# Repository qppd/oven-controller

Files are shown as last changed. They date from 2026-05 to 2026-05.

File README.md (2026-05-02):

## Oven Controller – Arduino‑Uno Embedded System
*Compact, menu‑driven oven controller with temperature & humidity sensing, scheduling, and PID‑based heating.*

---

## Overview
The Arduino‑based Oven Controller runs on an **Arduino Uno (AVR)** and provides a complete solution for managing a small oven or drying chamber.

**Key features**
- Real‑time temperature (DS18B20) & humidity (DHT22) monitoring
- RTC‑driven scheduling & timer (DS3231 + TimeAlarms)
- Heater & exhaust fan control via two relays
- 20×4 I²C LCD UI with three tactile buttons for menu navigation
- PID temperature regulation (PID_v1) with configurable set‑point (60‑125 °C)
- Flexible architecture: each hardware block lives in its own `.h/.cpp` pair

**Typical use‑cases**
- Laboratory drying oven
- Small food‑processing oven
- DIY thermal curing chamber

---

## System Architecture
```
+-------------------+      +-------------------+      +-------------------+
|   Arduino Uno     | ---> |   Hardware       | ---> |   External Power |
| (main sketch)    |      | (sensors, relays) |      |   & Safety Devices|
+-------------------+      +-------------------+      +-------------------+

+-------------------+      +-------------------+      +-------------------+
|   LCD (I2C)       | <--> |   Buttons (3)    | <--> |   User Interaction|
+-------------------+      +-------------------+      +-------------------+

+-------------------+      +-------------------+      +-------------------+
|   PID Controller  | <--> |   Temperature    |      |   Heater Relay   |
+-------------------+      +-------------------+      +-------------------+

+-------------------+      +-------------------+      +-------------------+
|   RTC (DS3231)    | <--> |   Alarms/Timers  |      |   Exhaust Relay   |
+-------------------+      +-------------------+      +-------------------+
```
- **Modular code**: each peripheral (LCD, relays, buttons, DHT22, DS18B20, DS3231, PID) has its own header and implementation file.
- **Separation of concerns**: hardware initialization, UI rendering, sensor acquisition, and control logic are isolated, making extensions (e.g., Wi‑Fi, EEPROM) straightforward.

---

## Hardware Components
| Component | Model / Library | Purpose |
|---|---|---|
| Arduino Uno | ATmega328P | Core MCU |
| DS18B20 | OneWire + DallasTemperature | Temperature sensor (pin 7) |
| DHT22 | DHT library | Humidity sensor (pin 8) |
| DS3231 | RTClib | Real‑time clock & calendar |
| 2× Relay modules | Direct `digitalWrite` | Heater (pin 2) & Exhaust fan (pin 3) |
| 20×4 I²C LCD | LiquidCrystal_I2C (0x27) | UI display |
| 3× Tactile buttons | Pull‑up inputs (pins 4‑6) | Menu navigation (UP, DOWN, SELECT) |
| I²C bus lines | SDA=A4, SCL=A5 | LCD communication |

**Pin configuration** (see `PINS_CONF.h`)
| Pin | Function |
|-----|---|
| 2 | Heater relay |
| 3 | Exhaust relay |
| 4 | Button 1 (UP) |
| 5 | Button 2 (DOWN) |
| 6 | Button 3 (SELECT) |
| 7 | DS18B20 temperature sensor |
| 8 | DHT22 humidity sensor |
| A4  | I²C SDA (LCD) |
| A5  | I²C SCL (LCD) |

---

## Software Architecture
| Module | Description |
|---|---|
| **OvenController.ino** | Main sketch: state machine, `setup()` / `loop()`, UI rendering, button handling, safety checks. |
| **LCD_CONF** (`LCD_CONF.h/.cpp`) | Wraps `LiquidCrystal_I2C`; provides `initLCD()`, `clearLCD()`, and overloaded `setLCDText()` for various data types. |
| **RELAY_CONF** (`RELAY_CONF.h/.cpp`) | Initializes relay pins and exposes `setHeaterRelay(bool)` / `setExhaustRelay(bool)`. |
| **TACTILE_CONF** (`TACTILE_CONF.h/.cpp`) | Handles button debouncing, state flags, and forwards button events to `inputAction(int)`. |
| **DHT_CONF** (`DHT_CONF.h/.cpp`) | Simple wrapper class `DHT22Sensor` exposing `begin()` and `readHumidity()`. |
| **DS18B20_CONF** (`DS18B20_CONF.h/.cpp`) | Wrapper class `DS18B20Sensor` exposing `begin()` and `readTemperature()`. |
| **DS3231_CONF** (`DS3231_CONF.h/.cpp`) | Global `RTC_DS3231` instance, `dsInitRTC()` for init, `dsHandleRTC()` for alarm processing and periodic time sync. |
| **PID_CONF** (`PID_CONF.h/.cpp`) | PID tuning (`P=4`, `I=0`, `D=22`), set‑points, runtime variables, `initPID()` and `computePID()` that drive the heater relay via time‑proportional control. |

The **state machine** (`OvenState`) cycles through: `IDLE → SET_TEMP → SET_TIMER → READY → RUNNING → FINISHED → ERROR`. Button actions transition states, and the LCD reflects the current state.

---

## System Flow
1. **`setup()`**
   - Serial init, LCD init, button init, relay init, LED pin, RTC init, sensor init, PID init.
   - Displays "Oven Ready".
2. **`loop()`** (executed continuously)
   - **Input handling** – `setInputFlags()` → `resolveInputFlags()` → calls `inputAction()` based on button pressed.
   - **Sensor read** – humidity via `DHT22Sensor`, temperature via `DS18B20Sensor`.
   - **Safety check** – if temperature > 130 °C → `stopOven()`, state = `ERROR`.
   - **PID** – temperature updates `CURRENT_TEMPERATURE`; `computePID()` calculates heater PWM and toggles relay.
   - **RTC** – `dsHandleRTC()` advances alarms, syncs time every minute.
   - **UI** – `renderLCD()` draws the appropriate screen for the current state.
   - Small `delay(10)` to ease CPU load.

**Simplified flow diagram**
```
setup() ──► init all peripherals
   │
   ▼
loop()
 ├─► read buttons → inputAction()
 ├─► read humidity & temperature
 ├─► safety cut‑off?
 │   └─► stopOven() & ERROR state
 ├─► PID compute → heater relay
 ├─► dsHandleRTC() (alarms & sync)
 └─► renderLCD()
```

---

## User Interface (Buttons + LCD)
| Button | Function |
|---|---|
| **UP** (pin 4) | Increment set‑point / timer |
| **DOWN** (pin 5) | Decrement set‑point / timer |
| **SELECT** (pin 6) | Advance to next screen / confirm action / start / stop / reset |

**Screens**
| State | LCD Content |
|---|---|
| **IDLE** | Current temperature, setpoint, "Press SELECT". |
| **SET_TEMP** | "SET TEMP", current set‑point, `BTN1:+  BTN2:-  BTN3:NEXT`. |
| **SET_TIMER** | "SET TIMER", minutes, same button hints. |
| **READY** | Shows target temperature & timer, `BTN3: START`. |
| **RUNNING** | Live temperature vs. set‑point, remaining timer, `BTN3: STOP`. |
| **FINISHED** | "DONE!", "Time Complete", `BTN3: RESET`. |
| **ERROR** | "ERROR – Overtemp", `BTN3: RESET`. |

---

## Control Logic
- **Set‑point range**: 60 °C – 125 °C (clamped in `SET_TEMP`).
- **Timer**: User‑selected minutes (1 – 180 min). `Alarm.timerOnce()` schedules `ovenStopCallback()`.
- **Relay behavior**
  - **Exhaust**: Always on during `RUNNING` for safety.
  - **Heater**: Controlled by PID output (0‑255) via time‑proportional window (1 s).
- **Safety**: Over‑temperature (>130 °C) forces immediate shut‑off and enters `ERROR`.

**PID defaults** (editable in `PID_CONF.cpp`)
```cpp
double P = 4.0;
double I = 0.0;
double D = 22.0;
double TEMPERATURE_SETPOINT = 100.0; // °C
```

---

## Timer & Scheduling
- **`dsInitRTC()`**: Starts I²C, initializes the DS3231, sets time from compile‑time if battery lost, and seeds TimeAlarms.
- **`dsHandleRTC()`**: Calls `Alarm.delay(1000)` each loop to advance the alarm engine, and resynchronises the Arduino `time()` with the RTC every 60 s.
- **`ovenStartAlarm()` / `ovenStopAlarm()`**: Example callbacks (currently hard‑coded to a placeholder relay pin).
- **`ovenTimer = Alarm.timerOnce(timerMinutes*60, ovenStopCallback);`** schedules a one‑shot stop alarm.

---

## Getting Started
1. **Install Arduino IDE** (or compatible CLI).
2. **Add libraries** via Library Manager or `Sketch → Include Library → Manage Libraries`
| Library | Header |
|---|---|
| LiquidCrystal_I2C | `LiquidCrystal_I2C.h` |
| OneWire | `OneWire.h` |
| DallasTemperature | `DallasTemperature.h` |
| DHT sensor library | `DHT.h` |
| RTClib | `RTClib.h` |
| TimeLib | `TimeLib.h` |
| TimeAlarms | `TimeAlarms.h` |
| PID_v1 | `PID_v1.h` |
3. **Wire the hardware** (see pin table above).
4. Open `src/uno/OvenController/OvenController.ino` in the IDE, select **Arduino Uno**, and click **Upload**.
5. Power the board, open the Serial Monitor (9600 baud) to see debug output, and interact with the LCD using the three buttons.

---

## Dependencies
- **Arduino core** (`Arduino.h`)
- **LiquidCrystal_I2C** – I²C LCD driver
- **OneWire** & **DallasTemperature** – DS18B20 communication
- **DHT** – DHT22 humidity sensor
- **RTClib** – DS3231 RTC handling
- **TimeLib** – time utilities (`now()`, `setTime()`)
- **TimeAlarms** – alarm & timer scheduling
- **PID_v1** – PID control algorithm
All libraries are publicly available through the Arduino Library Manager.

---

## Future Improvements
- Full PID tuning (auto‑tune, different window sizes).
- Persistent storage of set‑points & timer via EEPROM.
- Wi‑Fi / ESP32 migration for remote monitoring & OTA updates.
- Mobile or web dashboard (MQTT, HTTP).
- Additional safety sensors (over‑current, door switch).

---

## Troubleshooting
| Symptom | Likely cause | Fix |
|---|---|-----|
| LCD stays blank or shows "LCD error" | Incorrect I²C address or wiring | Verify address (`0x27`) with an I²C scanner; check SDA/SCL connections. |
| `Alarm.freeAll()` warning in Serial | TimeAlarms bug when freeing non‑existent alarms | Ensure `ovenTimer` is valid before calling `Alarm.free()`. |
| Compile error: multiple `RTClib` versions | Duplicate library versions in sketchbook | Keep only one version of `RTClib` (prefer the latest). |
| Relays never trigger | Pins not set as outputs or missing power | Confirm `initRelays()` runs; measure voltage on relay pins. |
| Over‑temperature shutdown immediately | Sensor wiring error or faulty DS18B20 | Test sensor separately; replace if readings are nonsensical. |

---

## License
**MIT License** – feel free to use, modify, and distribute this code.

---

## Author

<div align="center">

**Created with dedication by [qppd](https://github.com/qppd)**



</div>

---

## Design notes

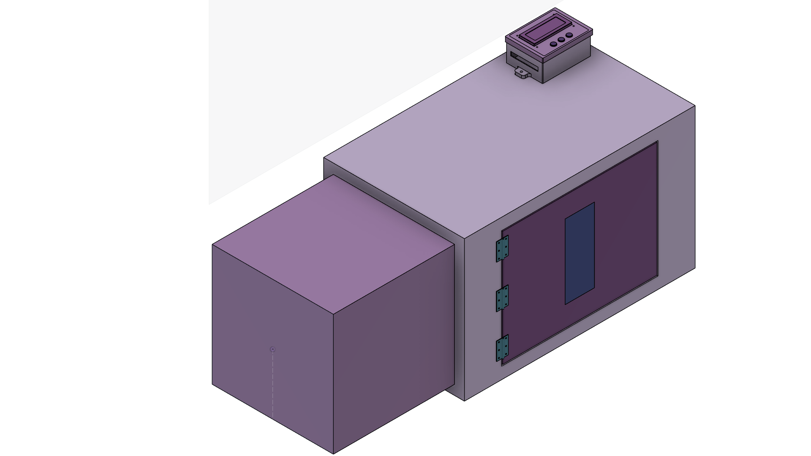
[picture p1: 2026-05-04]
fusion360/images/Oven_Controller_FL.png

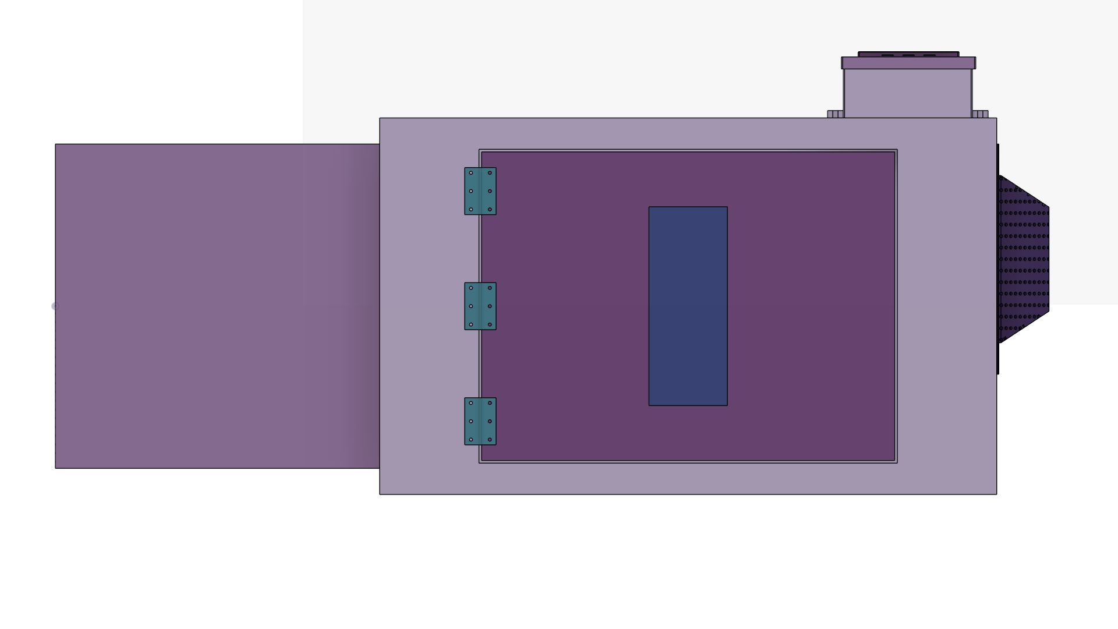
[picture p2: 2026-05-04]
fusion360/images/Oven_Controller_F.png

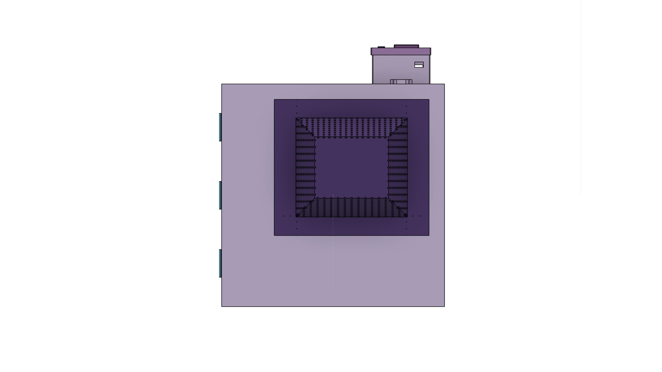
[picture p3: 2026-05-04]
fusion360/images/Oven_Controller_R.png

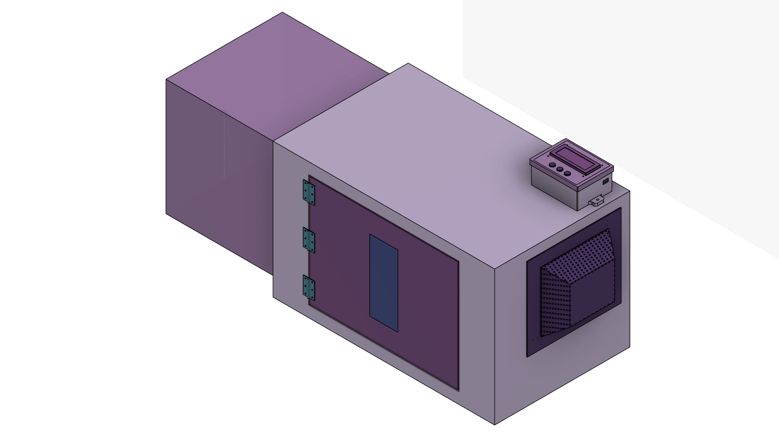
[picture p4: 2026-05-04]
fusion360/images/Oven_Controller_FR.png

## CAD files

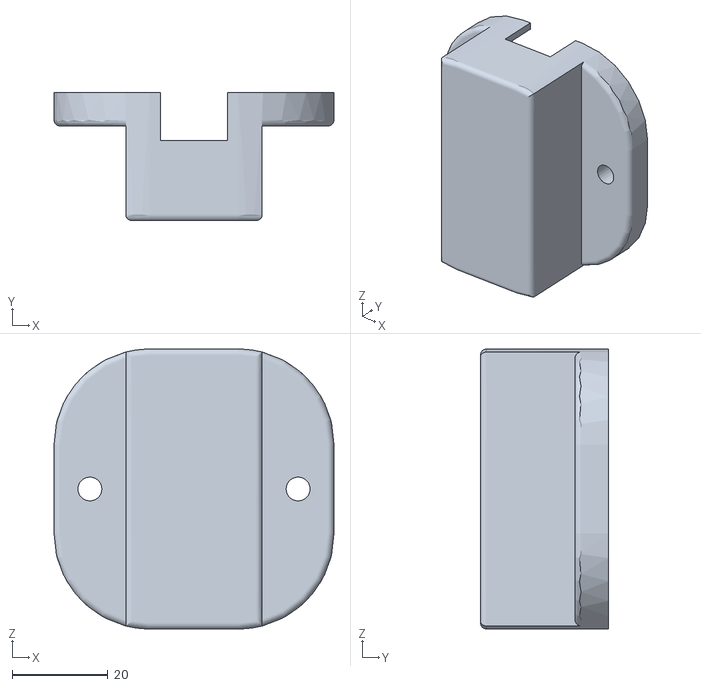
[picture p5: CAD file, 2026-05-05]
fusion360/STL/Oven_Controller_Temp_Sensor_Case.stl
58.5 x 26.8 x 58.5

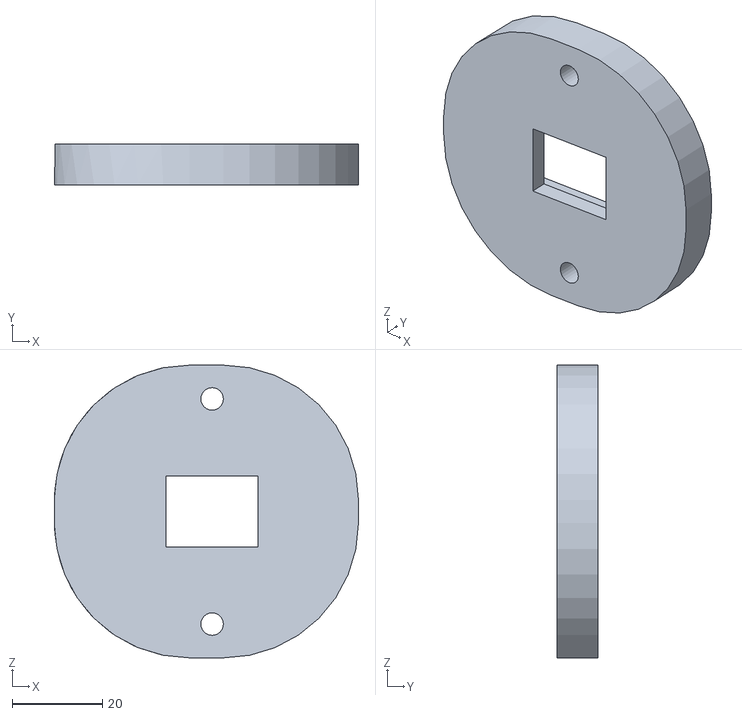
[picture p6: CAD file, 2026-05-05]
fusion360/STL/Oven_Controller_DHT22_Mount.stl
67.5 x 9.00 x 65.0

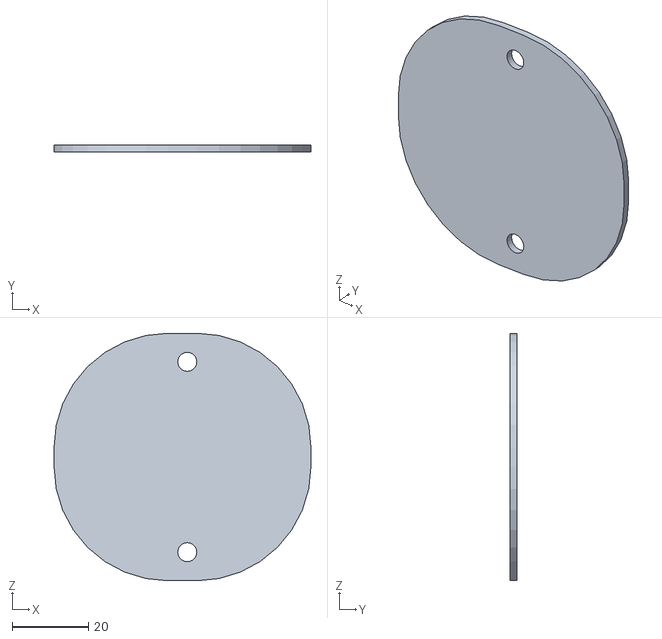
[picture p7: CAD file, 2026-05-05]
fusion360/STL/Oven_Controller_DHT22_Mount_Cover.stl
67.5 x 1.75 x 65.0

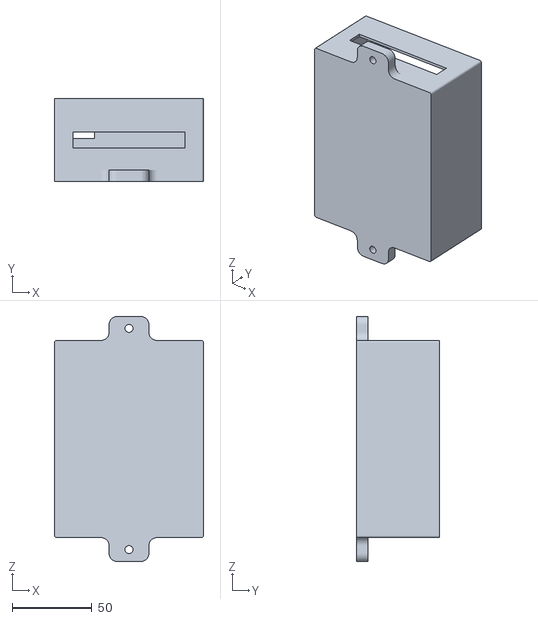
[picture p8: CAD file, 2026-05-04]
fusion360/STL/Oven_Controller_Case.stl
93.5 x 51.8 x 153.5

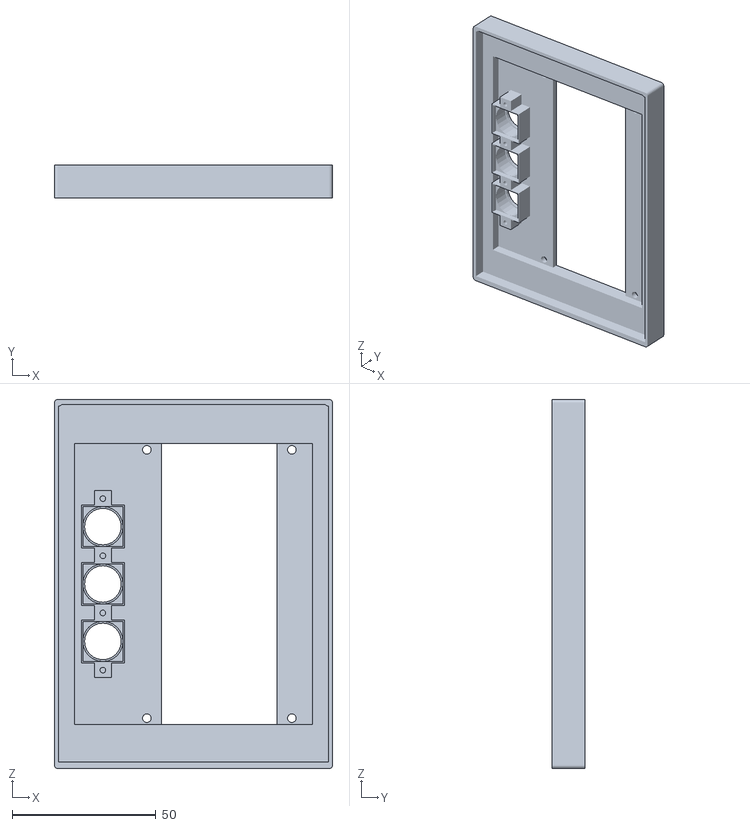
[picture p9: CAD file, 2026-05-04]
fusion360/STL/Oven_Controller_Case_Cover.stl
97.0 x 11.5 x 128.5

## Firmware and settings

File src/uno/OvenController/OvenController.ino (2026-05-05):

// Main Arduino sketch for OvenController

#include <stdio.h>
#include "LCD_CONF.h"
#include "UI_CONF.h"
#include "DS3231_CONF.h"
#include "TACTILE_CONF.h"
#include "RELAY_CONF.h"
#include "DHT_CONF.h"
#include "MAX6675_CONF.h"
#include "PID_CONF.h"

// -------------------------------------------------------------------
// Oven state machine definitions
// -------------------------------------------------------------------
// OvenState is now defined in UI_CONF.h
OvenState currentState = IDLE;

int timerMinutes = 0; // timer duration in minutes
AlarmId ovenTimer = dtINVALID_ALARM_ID; // track oven timer

// Sensors
DHT22Sensor dhtSensor(DHT22_PIN);
MAX6675Sensor tempSensor;

// Timing control for non-blocking updates
static unsigned long lastSensorRead = 0;     // Track sensor read timing
static unsigned long lastLCDUpdate = 0;      // Track LCD update timing
const unsigned long SENSOR_INTERVAL = 1000;  // Read sensors every 1000ms (1 sec)
const unsigned long LCD_INTERVAL = 500;      // Update LCD every 500ms (non-critical flicker fix)
static OvenState lastRenderedState = ERROR;  // Track last rendered state for change detection

// Temperature averaging - 10-reading circular buffer
const int TEMP_BUFFER_SIZE = 10;
static float tempBuffer[TEMP_BUFFER_SIZE] = {0.0};
static int tempBufferIndex = 0;
static int tempBufferFilled = 0;  // Count of actual readings
static float averagedTemperature = 0.0;

// Timer tracking for RUNNING state
static unsigned long ovenStartTime = 0;  // Timestamp when oven started
static unsigned long timerDurationMs = 0; // Total timer duration in milliseconds

// -------------------------------------------------------------------
// Setup
// -------------------------------------------------------------------
void setup() {
    Serial.begin(9600);
    while (!Serial) {;}

    // LCD
    initLCD();
    initUI();
    clearLCD();
    setLCDText("Oven Ready", 0, 0);

    // Buttons
    initBUTTONS();

    // Relays
    initRelays();

    pinMode(LED_BUILTIN, OUTPUT);

    // RTC
    dsInitRTC();

    // Sensors
    dhtSensor.begin();
    tempSensor.begin();

    // PID
    initPID();
}

// -------------------------------------------------------------------
// Main Loop - FULLY NON-BLOCKING
// -------------------------------------------------------------------
void loop() {
    // Button input check - ALWAYS responsive, NO BLOCKING
    setInputFlags();
    resolveInputFlags();

    // RTC handling - non-blocking alarm engine
    dsHandleRTC();

    // Sensor reads and temperature processing - THROTTLED to 1 second
    unsigned long currentMillis = millis();
    if (currentMillis - lastSensorRead >= SENSOR_INTERVAL) {
        lastSensorRead = currentMillis;

        // Read temperature from MAX6675 and add to averaging buffer
        float rawTemperature = tempSensor.readTemperature();
        
        // Add to circular buffer for averaging
        tempBuffer[tempBufferIndex] = rawTemperature;
        tempBufferIndex = (tempBufferIndex + 1) % TEMP_BUFFER_SIZE;
        if (tempBufferFilled < TEMP_BUFFER_SIZE) {
            tempBufferFilled++;
        }
        
        // Calculate average of buffered readings
        float sum = 0.0;
        for (int i = 0; i < tempBufferFilled; i++) {
            sum += tempBuffer[i];
        }
        averagedTemperature = sum / tempBufferFilled;
        CURRENT_TEMPERATURE = averagedTemperature;
        
        Serial.print("Temperature (raw): ");
        Serial.print(rawTemperature);
        Serial.print(" (avg): ");
        Serial.println(averagedTemperature);

        // Read humidity from DHT22
        float humidity = dhtSensor.readHumidity();
        Serial.print("Humidity: ");
        Serial.println(humidity);

        // Safety cutoff - only check on sensor read (use averaged temp)
        if (averagedTemperature > 130.0 || averagedTemperature < 0) {
            stopOven();
            currentState = ERROR;
        } else if (currentState == RUNNING) {
            // PID computation ONLY when oven is actually running
            computePID();
        }
    }

    // LCD rendering - THROTTLED to avoid flickering + on state change
    if ((currentMillis - lastLCDUpdate >= LCD_INTERVAL) || (currentState != lastRenderedState)) {
        lastLCDUpdate = currentMillis;

        // Trigger full refresh on state change
        if (currentState != lastRenderedState) {
            forceUIRefresh();
        }
        lastRenderedState = currentState;

        // Calculate remaining timer seconds
        unsigned long remainingSec = 0;
        if (currentState == RUNNING) {
            unsigned long elapsedMs = currentMillis - ovenStartTime;
            if (timerDurationMs > elapsedMs) {
                remainingSec = (timerDurationMs - elapsedMs) / 1000;
            }
        } else if (currentState == SET_TEMP || currentState == SET_TIMER || currentState == READY || currentState == IDLE) {
            remainingSec = (unsigned long)timerMinutes * 60UL;
        }

        updateUI(currentState, averagedTemperature, dhtSensor.getLastHumidity(),
                 TEMPERATURE_SETPOINT, timerMinutes, remainingSec);
    }
    
    // No delay() - loop runs as fast as possible for responsive input
}

// -------------------------------------------------------------------
// Button input handler
// -------------------------------------------------------------------
void inputAction(int index) {
    switch (currentState) {

        case IDLE:
            if (index == 2) currentState = SET_TEMP;
            break;

        case SET_TEMP:
            if (index == 0) TEMPERATURE_SETPOINT += 5;
            if (index == 1) TEMPERATURE_SETPOINT -= 5;
            if (index == 2) currentState = SET_TIMER;

            TEMPERATURE_SETPOINT = constrain(TEMPERATURE_SETPOINT, 60, 125);
            break;

        case SET_TIMER:
            if (index == 0) timerMinutes += 5;
            if (index == 1) timerMinutes -= 5;
            if (index == 2) currentState = READY;

            timerMinutes = constrain(timerMinutes, 1, 180);
            break;

        case READY:
            if (index == 2) {
                startOven();
                currentState = RUNNING;
            }
            break;

        case RUNNING:
            if (index == 2) {
                stopOven();
                currentState = IDLE;
            }
            break;

        case FINISHED:
            if (index == 2) currentState = IDLE;
            break;

        case ERROR:
            if (index == 2) currentState = IDLE;
            break;
    }
}

// -------------------------------------------------------------------
// Oven control
// -------------------------------------------------------------------
void ovenStopCallback() {
    setHeaterRelay(false);
    setExhaustRelay(false);
    currentState = FINISHED;
}

void startOven() {
    setExhaustRelay(true);
    
    // Track timer start time and duration for real-time display
    ovenStartTime = millis();
    timerDurationMs = (unsigned long)timerMinutes * 60000UL;  // Convert minutes to milliseconds

    ovenTimer = Alarm.timerOnce(timerMinutes * 60, ovenStopCallback);
}

void stopOven() {
    setHeaterRelay(false);
    setExhaustRelay(false);

    if (ovenTimer != dtINVALID_ALARM_ID) {
        Alarm.free(ovenTimer);
        ovenTimer = dtINVALID_ALARM_ID;
    }
}

// -------------------------------------------------------------------
// Helper Functions for Timer and Display
// -------------------------------------------------------------------
void getTimerDisplay(char* buffer, int bufferSize) {
    unsigned long elapsedMs = millis() - ovenStartTime;
    unsigned long remainingMs = (timerDurationMs > elapsedMs) ? (timerDurationMs - elapsedMs) : 0;
    
    int remainingMinutes = remainingMs / 60000;
    int remainingSeconds = (remainingMs % 60000) / 1000;
    
    snprintf(buffer, bufferSize, "%02d:%02d", remainingMinutes, remainingSeconds);
}

void getTemperatureDisplay(char* buffer, int bufferSize) {
    snprintf(buffer, bufferSize, "%.1f C", CURRENT_TEMPERATURE);
}

// -------------------------------------------------------------------
// LCD Rendering - Improved layout with proper field sizing
// -------------------------------------------------------------------
void renderLCD() {
    static char tempStr[10];
    static char timerStr[10];
    
    switch (currentState) {

        case IDLE:
            // Row 0: "Temp: XX.X C"
            setLCDText("Temp: ", 0, 0);
            getTemperatureDisplay(tempStr, sizeof(tempStr));
            setLCDText(String(tempStr), 6, 0);
            setLCDText("    ", 12, 0);  // Clear rest of line

            // Row 1: Empty
            setLCDText("                    ", 0, 1);

            // Row 2: "Set:  XX C"
            setLCDText("Set:  ", 0, 2);
            setLCDText(TEMPERATURE_SETPOINT, 6, 2);
            setLCDText(" C      ", 8, 2);

            // Row 3: "Press SELECT"
            setLCDText("Press SELECT        ", 0, 3);
            break;

        case SET_TEMP:
            // Row 0: "SET TEMPERATURE"
            setLCDText("SET TEMPERATURE     ", 0, 0);

            // Row 1: "Target: XX C"
            setLCDText("Target: ", 0, 1);
            setLCDText(TEMPERATURE_SETPOINT, 8, 1);
            setLCDText(" C          ", 10, 1);

            // Row 2: "BTN1:+  BTN2:-"
            setLCDText("BTN1:+  BTN2:-      ", 0, 2);

            // Row 3: "BTN3: NEXT"
            setLCDText("BTN3: NEXT          ", 0, 3);
            break;

        case SET_TIMER:
            // Row 0: "SET TIMER"
            setLCDText("SET TIMER           ", 0, 0);

            // Row 1: "Duration: XX min"
            setLCDText("Duration: ", 0, 1);
            setLCDText(timerMinutes, 10, 1);
            setLCDText(" min    ", 12, 1);

            // Row 2: "BTN1:+  BTN2:-"
            setLCDText("BTN1:+  BTN2:-      ", 0, 2);

            // Row 3: "BTN3: CONFIRM"
            setLCDText("BTN3: CONFIRM       ", 0, 3);
            break;

        case READY:
            // Row 0: "READY FOR START"
            setLCDText("READY FOR START     ", 0, 0);

            // Row 1: "Target: XX C"
            setLCDText("Target: ", 0, 1);
            setLCDText(TEMPERATURE_SETPOINT, 8, 1);
            setLCDText(" C          ", 10, 1);

            // Row 2: "Duration: XX min"
            setLCDText("Duration: ", 0, 2);
            setLCDText(timerMinutes, 10, 2);
            setLCDText(" min    ", 12, 2);

            // Row 3: "BTN3: START"
            setLCDText("BTN3: START         ", 0, 3);
            break;

        case RUNNING:
            // Row 0: "HEATING"
            setLCDText("HEATING             ", 0, 0);

            // Row 1: "Temp: XX.X / XX C"
            setLCDText("Temp: ", 0, 1);
            getTemperatureDisplay(tempStr, sizeof(tempStr));
            setLCDText(String(tempStr), 6, 1);
            setLCDText(" / ", 12, 1);
            setLCDText(TEMPERATURE_SETPOINT, 15, 1);
            setLCDText(" C", 17, 1);

            // Row 2: "Time: MM:SS"
            setLCDText("Time: ", 0, 2);
            getTimerDisplay(timerStr, sizeof(timerStr));
            setLCDText(String(timerStr), 6, 2);
            setLCDText("          ", 11, 2);

            // Row 3: "BTN3: STOP"
            setLCDText("BTN3: STOP          ", 0, 3);
            break;

        case FINISHED:
            // Row 0: "COMPLETE!"
            setLCDText("COMPLETE!           ", 0, 0);

            // Row 1: "Cycle finished"
            setLCDText("Cycle finished      ", 0, 1);

            // Row 2: Empty
            setLCDText("                    ", 0, 2);

            // Row 3: "BTN3: RESET"
            setLCDText("BTN3: RESET         ", 0, 3);
            break;

        case ERROR:
            // Row 0: "ERROR!"
            setLCDText("ERROR!              ", 0, 0);

            // Row 1: "Overtemp or fault"
            setLCDText("Overtemp or fault   ", 0, 1);

            // Row 2: "Temp: XX.X C"
            setLCDText("Temp: ", 0, 2);
            getTemperatureDisplay(tempStr, sizeof(tempStr));
            setLCDText(String(tempStr), 6, 2);
            setLCDText("     ", 12, 2);

            // Row 3: "BTN3: RESET"
            setLCDText("BTN3: RESET         ", 0, 3);
            break;
    }
}

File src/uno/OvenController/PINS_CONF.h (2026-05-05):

#pragma once
#include <Arduino.h>

// Pin assignments for OvenController hardware
// Relay 1 (heater & convection) -> pin 2
// Relay 2 (exhaust) -> pin 3
// Tactile buttons -> pins 9, 10, 11
// MAX6675 thermocouple -> pins 4, 5, 6 (DO, CS, CLK)
// DHT22 humidity sensor -> pin 8
// LCD uses I2C (default SDA=A4, SCL=A5 on Arduino Uno)

const int RELAY_HEATER_PIN = 2;   // Relay 1 controls heater and convection
const int RELAY_EXHAUST_PIN = 3;  // Relay 2 controls exhaust fan

const int BUTTON_PIN_1 = 10;       // Tactile button 1
const int BUTTON_PIN_2 = 9;      // Tactile button 2
const int BUTTON_PIN_3 = 11;      // Tactile button 3

const int DHT22_PIN    = 8;       // Humidity sensor pin

// MAX6675 Thermocouple pins
#define THERMO_DO   4
#define THERMO_CS   5
#define THERMO_CLK  6

// I2C pins for LCD (LiquidCrystal_I2C library)
const int LCD_I2C_SDA = A4;
const int LCD_I2C_SCL = A5;

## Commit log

2026-05-02 Integrate real PID_v1 control and full oven state machine.
    - Added PID implementation with windowed time‑proportional heating in PID_CONF.cpp.
    - Fixed TimeAlarms usage: tracked AlarmId, removed invalid freeAll(), added start/stop helpers.
    - Implemented OvenState enum, button handling, LCD UI updates, over‑temperature safety, and timer management in OvenController.ino.
    - Added global timerMinutes and ovenTimer tracking.
    - Updated renderLCD() to reflect each state on the 20×4 display.
    - Adjusted loop to use computePID(), safety checks, and LCD refresh.
    These changes provide accurate temperature regulation, user‑driven set‑point/timer UI, and reliable alarm handling.
    [DS3231_CONF.cpp, OvenController.ino]
2026-05-04 Updated 3d models
    [Oven_Controller_Case.stl, Oven_Controller_Case_Cover.stl]
2026-05-05 Updated controller
    [Oven_Controller_Temp_Sensor_Case.stl]
